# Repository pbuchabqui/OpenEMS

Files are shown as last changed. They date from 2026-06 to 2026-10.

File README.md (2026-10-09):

# OpenEMS

Fonte unica da verdade do projeto OpenEMS.

## Objetivo

OpenEMS e uma ECU para motores a combustao interna, atualmente focada no STM32H562RGT6. O codigo deve priorizar baixa latencia, baixo jitter e previsibilidade temporal para controle de injecao, ignicao, sensores e comunicacao de calibracao.

Este documento substitui os documentos historicos de plano, status e revisao. Qualquer decisao tecnica duravel deve ser atualizada aqui, nao em novos arquivos Markdown paralelos.

## Guia De Instalacao (10 passos)

Tudo pelo dashboard proprio (`tools/openems_dash`, aba **Install**: um guia
passo a passo com faixas validadas, lampada de ponto, teste de saidas, gravar,
exportar/importar tune e restaurar padroes de fabrica). O TunerStudio
(`tools/ts/openems.ini`, menu Install) continua funcionando como alternativa. Parametros
obrigatorios: **6** (cilindrada, vazao do injetor, AFR estequiometrico, curva
de dead time, offset do trigger, polaridade CKP/CMP). O resto ja vem com
valores de fabrica utilizaveis.

1. **Ligacao.** Roda 60-2 no CKP (PA0) e sensor de fase no CMP. Sensor Hall
   open-collector (repouso alto): polaridade "falling" (page0 byte 258).
2. **Motor** (Install → 1): cilindrada (cc), vazao do injetor
   (cc/min a 3 bar) e AFR estequiometrico (14.7 gasolina, 13.0 E30, 9.0 E100).
   Valor fora da faixa: so aquele campo e rejeitado, o resto e aplicado, e
   o canal `cfgReject` mostra qual campo (bit0 cilindrada, bit1 injetor,
   bit2 AFR, bit3 MAP ref, bit4 offset, bit5 EOI).
3. **Dead time do injetor** (Tuning → Injector Dead Time): copie a curva da
   folha de dados do injetor (ms vs tensao).
4. **Teste de saidas** (Install → 4, aba Outputs, motor parado): arme o teste;
   cada botao dispara um pulso no injetor ou bobina escolhidos. Confirme que
   injetor 1 e bobina 1 sao do cilindro 1, etc. "Exit" no fim (sai sozinho
   apos 5 s sem comando ou se o motor girar).
5. **Offset do trigger, grosso:** conte os dentes do primeiro dente apos a
   falha ate o PMS do cilindro 1 (compressao). Offset = (720 − dentes × 6) mod 720.
   Ex.: PMS 14 dentes depois → 720 − 84 = 636.
6. **Primeira partida:** sem pedal. O status `syncFull` deve acender e o RPM
   ficar estavel. Combustivel de partida = REQ_FUEL × multiplicador por CLT,
   igual com ou sem sensor de fase.
7. **Offset fino com lampada de ponto** (Install → 6): motor em marcha lenta,
   lampada no cabo da vela 1, ligue "Timing light mode" (centelha fixa em
   10.0°, sem correcoes nem knock). Ajuste "Trigger tooth0 offset" (1°) e
   "Fine offset" (0,1°) ate a lampada marcar 10°. Desligue o modo e grave
   (Burn). O modo nunca fica gravado: sempre desliga ao ligar a ECU.
8. **VE em marcha lenta:** com sonda wideband, ajuste a celula de VE da
   marcha lenta ate lambda ≈ alvo; depois ligue o closed loop e deixe o
   LTFT aprender o resto.
9. **Tabela de avanco:** comece conservador; o canal "Advance" mostra o
   avanco enviado as bobinas com 0,1° de resolucao (−20° a 60°). Knock
   atrasa so o cilindro que detonou.
10. **Gravar tudo** (Install → 7) antes de desligar. Exporte o tune para
    guardar uma copia; "Restaurar padroes de fabrica" volta aos valores do
    firmware (`tools/openems_dash/base_tune.json`, gerado do proprio firmware).

## Plataforma Alvo

- MCU: STM32H562RGT6, Cortex-M33.
- Revisao de silicio considerada: X.
- Linguagem: C++17 embarcado.
- Restricoes: sem STL em caminho critico, sem alocacao dinamica em runtime, sem excecoes.
- Build atual: `make firmware` gera `.elf`, `.hex` e `.bin` em `/tmp/openems-build`.

## Regras De Arquitetura

O fluxo de dependencias e descendente:

```text
APP     protocolos, calibracao, diagnostico
ENGINE  calculos de motor, agendamento angular, tabelas
DRV     decodificacao CKP/CMP, sensores, servicos independentes de MCU
HAL     registradores e perifericos STM32H562
HW      timers, ADC, GPIO, USB, CAN
```

Regras praticas:

- `APP` nao deve entrar no caminho critico de captura/agendamento.
- `ENGINE` decide tempo, angulo, pulso, dwell e estrategia.
- `DRV` transforma sinais fisicos em eventos de motor confiaveis.
- `HAL` contem apenas detalhe de periferico.
- O codigo ativo deve usar somente perifericos e nomes STM32H562 reais, sem aliases de compatibilidade.
- **`ENGINE` e `DRV` nao incluem headers `app/`.** Sinais de veiculo (marcha, velocidade, roda) entram via `engine/vehicle_inputs.h` (implementacao em `app/vehicle_inputs_bridge.cpp` → `can_rx_map`).
- **INJ/IGN GPIO:** mapas BSRR e write hot-path em `hal/out_pins.h` (`out_pin_write` inline). Init/safe em `out_pins_hw_init()`. `ecu_sched` nao reimplementa tabelas de pinos.
- Novos documentos Markdown paralelos nao devem ser criados; atualize este `README.md`.

## Escopo: so o firmware Hall

Este repo mantem um unico firmware: roda 60-2 + sensor de fase Hall, captura
em TIM5. A antiga regra "dual-firmware" (espelhar toda mudanca num tree de
encoder MT6835) foi abandonada na revisao de 2026-10; o tree encoder, se
retomado, porta as mudancas por conta propria.

## Pipeline De Controle Do Motor

### 1. Captura CKP/CMP

- Modulo principal: `src/drv/ckp.cpp`.
- Backend STM32: `src/hal/stm32h562/timer.cpp`.
- Timer usado: TIM5.
- Canais:
  - CKP: TIM5 CH1 em PA0.
  - CMP: TIM5 CH2 em PA1.

A captura mede bordas do virabrequim e comando, detecta dente faltante e alimenta a maquina de sincronismo. Classificacao por razao r = periodo / periodo de referencia:

- r < 0,5: ruido; descartado sem mover a referencia (o dente seguinte e medido certo).
- 0,5 ≤ r < 1,5: dente.
- r ≥ 1,5: candidato a gap; em FULL_SYNC so e aceito com exatamente 57 dentes desde o ultimo gap. Dente perdido ou a mais = perda de sync explicita, nunca ±6° silencioso.
- Pulso de ruido logo apos um dente curto e substituido quando o par fecha um periodo limpo.

Estados principais:

- `WAIT_GAP`: aguardando padrao confiavel de gap.
- `HALF_SYNC`: fase angular parcial suficiente para estrategias de partida rapida.
- `FULL_SYNC`: fase e ciclo conhecidos para injecao sequencial e ignicao correta.
- `LOSS_OF_SYNC`: falha de coerencia, ruido, timeout ou perda de padrao.

### 2. Quick Crank E Pre-Sync

- Modulos principais: `src/engine/quick_crank.cpp`, `src/engine/ecu_sched.cpp`.
- Objetivo: permitir primeira combustao antes do full sync quando tecnicamente seguro.

Estrategias permitidas antes de full sync:

- Injecao simultanea durante cranking.
- Injecao semi-sequencial quando a fase parcial permitir.
- Ignicao wasted spark antes da confirmacao completa de fase.
- Sem sensor de fase o motor roda em wasted spark por pares (0↔3, 1↔2), cada bobina no seu PMS.

A estrategia pre-sync deve degradar para modo conservador se houver duvida de fase. Partida rapida nao pode vencer seguranca de sincronismo.

### 3. Calculos De Combustivel E Ignicao

- Laco de 2 ms (sensores → PW/avanco/dwell → agendador): `src/engine/engine_calc.cpp` (`engine_calc_step`), testado de ponta a ponta em `test/test_engine_calc.cpp` e no motor virtual; `main_stm32.cpp` so le sensores, chama e publica telemetria.
- Combustivel: `src/engine/fuel_calc.cpp`.
- Ignicao: `src/engine/ign_calc.cpp`.
- Tabelas: `src/engine/table3d.cpp`.
- Sensores: `src/drv/sensors.cpp`.

Fluxo esperado:

```text
ADC/TIM6 -> sensors -> fuel_calc/ign_calc -> ecu_sched -> TIM5_CH3/BSRR -> atuadores
```

Os calculos usam RPM, MAP, TPS, CLT, IAT, lambda e calibracoes. Tabelas devem operar com interpolacao deterministica e sem custo imprevisivel no caminho critico.

Combustivel por speed density com oraculo fisico nos testes (`test/test_fuel_physics.cpp`): PW = REQ_FUEL × VE × MAP/101,325 kPa × T_ref/T, ΔP do injetor por √ΔP, filme de parede X-τ (Aquino), LTFT integrando o STFT. Interpolacao de tabelas e curvas arredonda ao mais proximo (sem vies). Partida: REQ_FUEL × multiplicador(CLT), igual em HALF e FULL sync.

Avanco em decimos de grau de ponta a ponta (tabela interpolada a 0,1°, correcoes em 0,1°, faixa unica −20° a 60°). Retardo de knock por cilindro (`ecu_sched_set_cyl_retard_x10`). O laco de 2 ms recalcula e faz commit a cada tick (`ecu_sched_commit_calibration_x10`).

### 4. Scheduling De Injecao E Ignicao

- Modulo principal: `src/engine/ecu_sched.cpp`.
- Injecao **e** ignicao: mesmo dispatcher **TIM5_CH3** (output compare) + fila
  ordenada de eventos absolutos; a saída física é feita por **GPIO BSRR**
  (`hal/out_pins.h`, `out_pin_write` inline). Sem TIM2/TIM8 OC no caminho INJ/IGN.
- Base temporal: TIM5 32-bit @ **62.5 MHz** (16 ns/tick), livre-corrente e
  partilhado com a captura CKP/CMP (CH1/CH2).

Premissa de projeto:

- O caminho critico é agendado por hardware output compare (TIM5_CH3): o OC arma
  o tick de despacho e a ISR escreve o BSRR do canal — não há bit-bang em espera.
- A ISR arma o proximo evento e actualiza estado; a escrita GPIO só é permitida
  header-inline (`out_pin_write`), nunca lógica de fila noutro `.cpp`.
- Janelas longas devem lidar com limite de contador por rearmamento/near-time, sem perder precisao perto do evento.
- Eventos vencidos devem ser tratados explicitamente, nunca silenciosamente aceitos.

Precisao (medida no motor virtual, `make precision-test`):

- SPARK e INJ_ON sao angulares: tabela por dente (dente de armamento + fracao
  1/256 de dente), ancorada na captura do dente, nao no instante da ISR.
  Eventos dentro do gap (348–360°) sao agendados corretamente.
- INJ_OFF = INJ_ON + PW em ticks; DWELL_START = centelha − dwell em ticks:
  largura de pulso e dwell exatos em tempo, independentes de aceleracao.
- Erro de centelha ≤ 0,01° em regime, ≤ 0,5° a ±2700 rpm/s, ≤ 0,2° com jitter de 1 µs.

Eventos de injecao e ignicao ficam codificados no scheduler do motor, nao num
driver legado. O scheduler recebe dentes/angulo do CKP, calcula quando cada canal
deve abrir/fechar (INJ) ou fazer dwell/centelha (IGN) e insere-os na mesma fila
despachada por TIM5_CH3. Ordem de canais BSRR em `docs/hw/pinout.md`.

### 4a. Detecção De Knock (Detonação)

- Sensor piezoelétrico knock conectado em PA5/ADC1_IN6.
- Hardware: filtro passa-banda externo → PA5 → ADC1.
- Detecção: software via threshold ADC (STM32H562 não possui periférico COMP).
- Amostragem: `knock_adc_update(raw)` chamado de `sample_fast_channels()` 12×/rev (acumulador `kFastSamplesPerRev`, não a cada dente CKP) durante janela ativa.
- Threshold ADC: padrão 2048 (12-bit), range [256, 4000].
  - Adaptativo: -64 por evento de knock; ciclos limpos devolvem +32, nunca acima do valor calibrado (sem deriva que desligue a deteccao).
- Janela de knock: `knock_window_cycle_end()`/`knock_window_open()` ligados a `arm_channel()` no evento `ECU_ACT_DWELL_START` (modo sequencial), atrás da flag `EMS_KNOCK_HW_PRESENT` (`hal/board_pinout.h`, default 0 — front-end analógico DNP na v1, `docs/hw/schematic/10_knock_dnp.md`). Com a flag em 0 a janela nunca abre de facto.
- Retardo: +2,0° por evento de knock, máximo 10,0°.
- Recuperação: -0,1° por ciclo limpo após 10 ciclos consecutivos limpos.
- Retardo por cilindro: so a bobina do cilindro que detonou atrasa.
- Persistência NVM: retardo em slot knock; o threshold nao e gravado (volta ao calibrado no boot).

### 5. Atuadores e pinout (firmware)

**Pinout completo: [`docs/hw/pinout.md`](docs/hw/pinout.md)** — mapa por pino dos
dois packages, conflitos WeAct e fiação. Código de referência: `ecu_sched.cpp`
(INJ/IGN BSRR), `hal/out_pins.h` (`static_assert` por board), `etb_driver.cpp`,
`timer.cpp`, `adc.cpp`. O firmware selecciona o package no **build**:

```bash
make firmware BOARD=rgt6   # default — WeAct LQFP64 (INJ/IGN em A/B/C)
make firmware BOARD=vgt6   # LQFP100 (INJ/IGN/ETB em PE*, BSRR único)
# bins: /tmp/openems-build/bin/openems-{rgt6,vgt6}.bin
```

Resumo das diferenças (o RGT6 **não tem port E** → INJ/IGN/ETB redistribuídos):

| Função | **RGT6** (default) | **VGT6** |
|---|---|---|
| CKP / CMP | PA0 / PA1 (TIM5) | igual |
| UART / USB / CAN / LED | PA9-10 / PA11-12 / PB8-9 / PB2 | igual |
| INJ1–4 | PA15 / PB3 / PC10 / PC11 | PE0 / PE2 / PE4 / PE6 |
| IGN1–4 | PC6 / PC7 / PC8 / PC9 | PE9 / PE11 / PE13 / PE15 |
| ETB PWM / DIR | PA6 (TIM3) / PA8 / PB4 | PE5 (TIM15) / PE7 / PE8 |
| INJ/IGN drive | GPIO BSRR (A/B/C) | GPIO BSRR (só GPIOE) |

ADC (comum aos dois): MAP PA3 · TPS PA4 · KNOCK PA5 · ETB_TPS1/2 PA2/PC5 · APP1/2
PC0/PC2 · CLT PB0 · IAT PB1 · FUEL_P PC4 · OIL_P PC1 · EWG_POS PC3. WBO2 λ só via
CAN (sem ADC O2). Tabela ADC completa (ADC1/2 + INP): `docs/hw/pinout.md`.

**Trocar de placa:** gravar o binário correcto (`BOARD=…`); flash cruzado = pinos
errados. Boot safe: `ecu_sched_outputs_safe_early()` → `out_pins_hw_init()`
(RGT6: PA15 JTDI pull-up; VGT6: PE\* LOW). Actuadores active-high.

## ADC E Sensores

- Modulos: `src/hal/adc.cpp`, `src/hal/stm32h562/adc.cpp`, `src/drv/sensors.cpp`.
- ADC primario/secundario representam ADC1/ADC2 no STM32.
- ADC 12-bit 0–3.3 V (raw 4095), tensão aceite pelo STM32H5. MAP 0–3.3 V → 0–3.00 bar (`raw × 3000 / 4095`). TPS/APP/ETB default 0–4095.
- TIM6 deve ser o gatilho periodico de amostragem.
- Validacao de sensores deve bloquear valores absurdos e preservar estado de falha para diagnostico.

## Comunicacao

- Protocolo em `src/app/ui_protocol.cpp`, dual-mode com auto-detect por frame:
  - **Legacy** (ASCII cru, sem envelope): comandos `Q/S/F/C/A/O/r/w/x/b/d/B/G/P/V/D`,
    usados por `tools/openems_dash/protocol.py`, `tools/lib/ecu_link.py`, HIL e diag.
  - **TunerStudio** (envelope `msEnvelope_1.0`): `[size u16 BE][cmd+dados][CRC32 BE]`;
    detectado quando o primeiro byte em IDLE e < 0x20 (byte alto do size). Respostas
    levam response code (0x00 OK, 0x82 CRC, 0x83 cmd, 0x84 range, 0x85 busy) + CRC32.
    Projeto TunerStudio: `tools/ts/openems.ini` (assinatura `OpenEMS_v1.2`).
    No envelope, `w` e chunk-write **RAM-only**; burn e explicito via `b`.
- Burn de Flash via protocolo (`w` legacy sem RAM-only, `b` em ambos os modos) e
  bloqueado quando `rpm_x10 > kFlashWriteSafeRpmX10` (errata ES0565: primeira
  escrita/erase pode congelar fetch ~120 us). Legacy devolve NACK; envelope 0x85.
- Pagina 11 (64 B): eixos das tabelas 16x16 (16xu16 RPM + 16xu16 load bar x100),
  editaveis com validacao de monotonicidade estrita; NVM setor 10 (slot 9).
- MVP de bancada: UART 115200 8N1 em `USART1` (`PA9=TX`, `PA10=RX`). O shuttle
  UART<->protocolo roda no slot de 2 ms (`comms_pump()`), nao-bloqueante, com
  TX FIFO (FIFOEN) — throughput efetivo ~4 kB/s, suficiente para realtime TS a
  10-20 Hz. USB CDC espelha o TX e mantem RX no slot de 20 ms.
- USB CDC: driver USB DRD FS completo (`hal/stm32h562/usb_cdc.cpp`), ainda nao validado em
  hardware; ate la a UART e o transporte de referencia.
- CAN/FDCAN: diagnostico e integracao com sensores externos.

Comunicacao nao deve bloquear decode, sync, scheduling ou atuadores.

## Errata STM32H562 ES0565

Referencia local revisada: `es0565-stm32h562xx563xx573xx-device-errata-stmicroelectronics.pdf`, Rev 8, January 2026.

Impactos diretos no projeto:

- Revisao operacional considerada: X. Antes de teste real, confirmar a revisao fisica por marcacao do chip e `REV_ID` em `DBGMCU_IDCODE`, e registrar essa evidencia antes de liberar ensaio com atuadores.
- PA1 tem errata de histerese na revisao A: a histerese de entrada de PA1 so e habilitada quando PA0 esta configurado como entrada. Como CMP usa `PA1/TIM5_CH2`, revisao A exige condicionamento externo robusto ou troca de pino/placa. Em revisoes Z/X/W a limitacao consta como ausente.
- Flash tem limitacao de endurance de 1 kcycle nas revisoes A/Z. NVM/calibracao/seed de sincronismo nao podem gravar com alta frequencia. Para teste real, tratar Flash como recurso de baixa taxa e preferir commit explicito/event-driven.
- A primeira operacao de erase/program apos power-on ou Standby pode congelar fetch/read de Flash por cerca de 120 us. O caminho critico de CKP/scheduler nao deve depender de escrita Flash durante motor girando. Workaround completo exige vetor/handlers criticos e rotina da primeira escrita em SRAM.
- Read-while-write em Flash aumenta latencia em revisoes A/Z. Nao executar erase/program em Bank2 durante janela critica de injecao/ignicao/CKP.
- ADC: manter amostragem regular disparada por TIM6. Nao usar fila de conversoes injetadas, modo dual interleaved, watchdog analogico misturado com canais nao guardados ou stop de conversao injetada sem aplicar os workarounds da errata.
- FDCAN: nao habilitar edge filtering (`EFBI`) e evitar mistura de dedicated Tx buffer com Tx FIFO em prioridades diferentes. Se FDCAN1/FDCAN2 forem usados juntos, manter o mesmo nivel TrustZone/privilegio nos dois. O backend atual deve permanecer simples: sem edge filtering e com disciplina de fila unica/buffer unico.
- USB: em transferencias OUT, a SRAM USB pode ainda estar sendo atualizada quando o CTR dispara. Driver USB real deve inserir atraso minimo antes de ler buffer OUT: 800 ns em Full Speed.
- TIM: conexao de USB SOF para TIM2/TIM5 ITR12 pode falhar; o projeto nao deve usar USB SOF como referencia temporal de motor. Toda a base temporal do motor (captura CKP/CMP e dispatcher de INJ/IGN) vive em TIM5 e nao depende de USB SOF.
- IWDG nao acorda o sistema de Stop mode. O projeto de ECU nao deve depender de Stop mode para recuperacao por watchdog.

Conclusao operacional: considerando silicio Rev X, a limitacao de histerese em PA1/CMP e as limitacoes de endurance/read-while-write de Flash das revisoes A/Z nao sao bloqueios esperados. Continuam relevantes em Rev X: congelamento da CPU na primeira escrita/erase de Flash, cautelas de ADC, FDCAN, USB, TIM USB SOF e IWDG em Stop mode. Placa WeAct e firmware atual seguem adequados para bancada sem atuadores energizados. Teste real de motor ainda exige confirmar fisicamente a Rev X, limitar escrita Flash durante motor girando e validar USB/FDCAN/ADC com os workarounds acima.

## Build

Compilar objetos do firmware:

```bash
make firmware
```

Executar regressao host minima do MVP de bancada:

```bash
make host-test
```

Limpar artefatos:

```bash
make clean
```

## Higiene De Codigo

Programa de qualidade do monorepo (concluido 2026-07; HEAD tipico inclui
`fa36aab` e anteriores `713d4a8`…`bce2f4a`). Objectivo: reviews limpos, zero
warnings com `WERROR`, camadas enforcadas e caminho critico de actuadores
isolado sem big-bang rewrite.

### Gates locais (obrigatorios antes de merge)

```bash
make ci-local                   # todos os gates abaixo
# equivalentes manuais:
make secrets-check
make host-test WERROR=1         # referencia: 1341 PASS / 0 FAIL
make precision-test             # motor virtual: 120 PASS / 0 FAIL (centelha, dwell, PW, EOI)
make ini-check                  # TunerStudio ini: referencias, sobreposicao, faixas = firmware
make dash-check DASH_PY=<venv>/bin/python  # dashboard: helpers JS + protocolo vs ECU simulada
make sim-ecu NVM=/tmp/nvm.bin   # ECU simulada num pty para o dashboard (sem placa)
make firmware-rgt6 WERROR=1
make firmware-vgt6 WERROR=1
make lint-includes LINT_PHASE=A LINT_ERROR=1   # ban ENGINE/DRV → app/
make lint-includes LINT_PHASE=B LINT_ERROR=1   # ban ENGINE → hal/regs.h (allowlist)
make format                     # clang-format so em ficheiros dirty (on-touch)
```

| Gate | Target | Notas |
|---|---|---|
| Warnings | 0 com `-Wall -Wextra` | Host **e** firmware dual board |
| Secrets tracked | 0 | `**/wifi_credentials.h` gitignored |
| Layering A | 0 includes `app/` em `src/engine`, `src/drv` | `tools/lint_includes.py` |
| Layering B | `hal/regs.h` so em engine com allowlist | `tools/include_allowlist.txt`: `ecu_sched` (TIM5), `auxiliaries` (fan/pump ate Phase C) |
| Host tests | PASS exacto estavel | Suites em `test/test_*.cpp` + `run_all.cpp` |
| Dual board | bins rgt6 + vgt6 | Qualquer mudanca de pin/HAL |

### Layout de testes host

| Ficheiro | Papel |
|---|---|
| `test/harness.{h,cpp}` | `CHECK_*`, contadores PASS/FAIL |
| `test/fixtures.{h,cpp}` | setup ADC/ETB, `ckp_fire` / `cam_fire` |
| `test/ui_helpers.{h,cpp}` | envelope TunerStudio para testes de protocolo |
| `test/run_all.cpp` | `main()` — **ordem fixa** das suites |
| `test/suite_registry.h` | declaracoes das funcoes `test_*` |
| `test/test_*.cpp` | suites (etb, torque, ckp, fuel, sched, protocol, …) |
| `test/sim/engine_sim.{h,cpp}` | motor virtual: cinematica θ(t), roda 60-2 real + came, jitter/ruido, modelo de latencia da ISR, log de pinos com timestamp |
| `test/sim/precision_main.cpp` | `make precision-test`: compara o que o motor recebe (angulo de centelha, dwell, combustivel, EOI) com o oraculo cinematico; defeitos conhecidos = XFAIL com a etapa que os corrige |

Host: um unico TIM5 simulado (`hal/tim5_host.h`) e partilhado por captura
CKP/CMP, comparador do scheduler e `tim5_count()`; `out_pin_write` expoe um
hook (`out_pins_host::write_hook`) para o simulador registar cada transicao.

Nao reintroduzir monolitio `mvp_bench_tests.cpp`. Novos testes: ficheiro de suite
existente ou novo `test_*.cpp` + registo em `run_all.cpp` e `suite_registry.h`.

### Camadas — contratos pos-higiene

**Vehicle inputs (ENGINE ← APP):**

```text
can_stack → can_rx_map_process (APP)
torque_manager / auxiliaries → vehicle_gear|speed|wheel (engine/vehicle_inputs.h)
                            → vehicle_inputs_bridge.cpp (APP) → can_rx_*
```

Page0 serialize/apply do mapa CAN permanece em APP (`can_rx_map_*_page0`).

**INJ/IGN outputs (HAL):**

```text
ecu_sched gpio_set_pin → ems::hal::out_pin_write  (inline em out_pins.h)
ecu_sched_outputs_safe_early → out_pins_hw_init()  (clocks + MODER + BSRR LOW)
```

Ordem de canais BSRR = `ECU_CH_*`:
`[INJ3, INJ4, INJ1, INJ2, IGN4, IGN3, IGN2, IGN1]`. Actuadores active-high;
safe = LOW. Testes de polaridade RGT6: `test_out_pins_bsrr_rgt6`.

Hot-path rule (`ecu_sched_internal.h`): nao mover `evt_insert` / arm / dispatch
para outro `.cpp`; write GPIO so e permitido se **header-inline** (como
`out_pin_write`).

**NVM boot:** loaders de tabelas/correccoes em `app/nvm_boot.cpp`
(`nvm_boot_load_tables(cal_layout_ok)`), chamados de `main_stm32` — mesma
ordem e gate de layout de antes.

**UI protocol:** `ui_protocol.cpp` (parse + API) + `ui_protocol_state.cpp` +
`ui_protocol_pages.cpp` + `ui_protocol_envelope.cpp` + `ui_protocol_internal.h`.

**ETB PWM:** API preferida `etb_pwm_init` / `etb_pwm_set_duty_x10`. Aliases
`tim15_etb_*` deprecated em `hal/timer.h`.

### Secrets e vendor

- WiFi tools ESP32: copiar `wifi_credentials.example.h` → `wifi_credentials.h`
  (nunca commitado). Se password ja esteve no historico git, **rodar no AP**.
- `graphify-out/` e bins/fonts pesados do `ardustim_gui` nao sao versionados
  (regenerar graphify / `npm install` localmente). GUI Electron continua
  documentada em `tools/esp32_combined/README.md`.

### Docs

| Documento | Papel |
|---|---|
| **README.md** (este) | Fonte unica de decisoes duraveis |
| `docs/bench_test_manual.md` | Teste de bancada na WeAct VGT6 (sem atuadores) |
| `docs/hw/pinout.md` | **Pinout completo** RGT6/VGT6 (detalhe movido do §5) |
| `docs/wiring_diagram.md` | Esquemáticos eléctricos (mapa de pinos ASCII **legado**) |
| `docs/ROADMAP.md` | Backlog de produto (ADC residual, SD, …) |
| `docs/*.md` | Subsistemas (fuel, idle, …) |

### Fora de escopo do programa de higiene (opcional)

- `hal/aux_gpio` para fan/pump (hoje `auxiliaries.cpp` ainda usa `regs.h` /
  BSRR — allowlist Phase C).
- Split adicional de monolitios grandes (`ckp.cpp`, `fuel_trim`, etc.).

## MVP Bancada Segura

Definicao de pronto para o MVP de bancada:

- `make firmware` gera `.elf`, `.hex` e `.bin`.
- `make host-test` cobre regressao minima (suites em `test/test_*.cpp` + `run_all.cpp`): CKP 60-2, quick crank, scheduler, tabelas, protocolo UI, ETB, torque, fuel/ign, X-τ, etc.
- Firmware sobe na STM32H562 com ST-Link, sem bobinas/injetores energizados, sem reset loop ou hard fault.
- TIM5 recebe CKP/CMP sintetico de 200 a 8500 rpm e telemetria mostra transicoes `WAIT_GAP`, `HALF_SYNC`, `FULL_SYNC`, perda e retomada de sync.
- As saídas INJ/IGN (GPIO BSRR, despachadas por TIM5_CH3) geram sinais verificaveis em osciloscopio para cranking, half-sync, full-sync, loss-of-sync e zero RPM.
- ETB (PWM PA6/TIM3 no rgt6, PE5/TIM15 no vgt6) permanece desligado até `etb_cal_valid==1 && !throttle_fault_bits`.
- UI bridge usa UART `PA9/PA10` a 115200 8N1 para assinatura, realtime data e escrita pequena de calibracao.
- Durante ensaio, registrar `loop2_last`, `loop2_max`, `late_event_count`, `cycle_schedule_drop_count` e `calibration_clamp_count`.

### CAN TX Frames

| ID | Cadência | Layout |
|---|---|---|
| 0x400 | 10 ms | RPM(2LE) · MAP_kpa(1) · TPS_pct(1) · CLT+40(1) · advance+40(1) · PW_x10(1) · StatusBits[7:0](1) |
| 0x401 | 100 ms | FuelP_kpa(2LE) · OilP_kpa(2LE) · IAT+40(1) · STFT+100(1) · StatusBits[15:8](1) · VVT_ex_pct(1) |
| 0x402 | 500 ms | FuelAccum_ul(4LE) · FuelDelta_ul(2LE) · reservado(2) |

### Status Bits (16-bit, split entre 0x400 e 0x401)

- Bits 0-7 transmitidos em `0x400 data[7]`; bits 8-15 em `0x401 data[6]`.
- Bits definidos em `src/app/status_bits.h`:
  - `STATUS_SYNC_FULL` (bit 0): sincronismo CKP/CMP completo.
  - `STATUS_PHASE_A` (bit 1): fase parcial disponível.
  - `STATUS_SENSOR_FAULT` (bit 2): falha em sensores analógicos.
  - `STATUS_LIMP_MODE` (bit 3): modo de emergência ativo.
  - `STATUS_ETB_LIMP` (bit 4): ETB em modo limp (limite reduzido).
  - `STATUS_XTAU_LEARN` (bit 5): autocalibracao X-τ em progresso.
  - `STATUS_SCHED_LATE` (bit 6): evento de scheduler atrasado.
  - `STATUS_SCHED_DROP` (bit 7): evento descartado no scheduler.
  - `STATUS_SCHED_CLAMP` (bit 8): ajuste limitado na calibracao — em `0x401 data[6]` bit 0.
  - `STATUS_WBO2_FAULT` (bit 9): sensor WBO2 offline — em `0x401 data[6]` bit 1.
  - bit 10 reservado (era TLE8888_FAULT; sempre 0), `STATUS_IGN_SEQUENTIAL` (bit 11), `STATUS_REV_LIMIT` (bit 12).
  - `STATUS_LAUNCH_ACTIVE` (bit 13): launch control holding ETB/RPM.
  - `STATUS_TC_ACTIVE` (bit 14): traction control reducing torque.
  - OCH also exposes `tcReduction` (%×10 @ off 45) and `torqueSparkRetard` (deg @ off 47).

### ETB (Electronic Throttle Body)

- PWM: **PA6 TIM3_CH1** (rgt6) ou **PE5 TIM15_CH1** (vgt6), 20 kHz (`etb_pwm_init`).
- H-bridge dual-DIR (BTS7960/VNH5019-style): IN1 open / IN2 close — rgt6 **PA8/PB4**,
  vgt6 **PE7/PE8** (ver `docs/hw/pinout.md`).
- Boot policy: ETB desativado (`EN=0`, PWM=0) até calibracao valida e sensores OK.
- **Auto-cal de power-on** (`src/engine/etb_autocal.{h,cpp}`): a cada boot varre a
  borboleta aos batentes (fechado→aberto) no tick de 2 ms, ANTES do torque manager
  assumir, e aplica os limites TPS1/TPS2 em RAM. Aborta mantendo a cal de flash se o
  motor girar, o driver faltar ou o curso for implausível (span/invertido). O
  `EtbCalRecord` (16 B, magic `EC` + CRC-32, setor adaptativo) persiste a última cal
  boa como **fallback** quando uma partida interrompe a varredura do power-on
  seguinte (`nvm_save_etb_cal` / `nvm_load_etb_cal`). O pedal (APP) continua manual.
- Plausibilidade dual-sensor (pinos = `src/hal/adc.cpp` / `docs/hw/pinout.md`):
  - APP plausibilidade: compara APP1 vs APP2 (**PC0 / PC2**), gera `THROTTLE_FAULT_APP_PLAUS` se delta exceder limite.
  - ETB_TPS plausibilidade: compara ETB_TPS1 vs ETB_TPS2 (**PA2 / PC5**), gera `THROTTLE_FAULT_ETB_PLAUS` se delta exceder limite.
  - Delta máximo default: 12% entre sensores redundantes.
- Falhas: `THROTTLE_FAULT_APP1/APP2/APP_PLAUS` bloqueiam demanda; `THROTTLE_FAULT_ETB_*` entram em limp mode com `etb_max_open_pct_x10_limp` (default 25%).
- RATE limits: `etb_max_rate_pct_per_s` (default 500 %/s).
- Gating do torque manager:
  - Falhas APP (`THROTTLE_FAULT_APP1/APP2/APP_PLAUS`): limitam abertura do ETB (limp home) mas nao desativam o enable request.
  - Falhas ETB (`THROTTLE_FAULT_ETB_TPS1/ETB_TPS2/ETB_PLAUS`): desativam o enable request do ETB via `etb_enable_request = false`.

### X-τ Autocalibracao

- Executa no slot 100ms, gated por: RPM > 2000, STFT ±500 limites, lambda valido, AE inativo.
- Bloqueio de intervalo: `kLearnIntervalMs = 60000u` (mínimo 60s entre aprendizados consecutivos).
- Deadband STFT: não aprende quando `|STFT| <= 20` (±20% deadband).
- Ajuste lento: 1 LSB por minuto max, clamp aos limites de tabela (1..255 ciclos).
- Persistencia: RAM only, salva em NVM page 6 via burn explícito (nunca durante motor girando).
- Safety: nunca executa erase/program durante janela critica de CKP/scheduler.

Fora do MVP de bancada:

- Primeira partida de motor real.
- USB CDC real.
- Operacao com atuadores reais energizados sem validacao previa de pinout, polaridade, cargas dummy e limites de Flash.

## Estado Atual

- Codigo ativo direcionado ao STM32H562.
- Backend de timers STM32: TIM5 (CKP/CMP + dispatcher INJ/IGN CH3), TIM6 (trigger ADC), TIM2 (EWG PWM), TIM3 (ETB PWM rgt6), TIM15 (ETB PWM vgt6), TIM4 (VVT).
- Scheduler principal consolidado em `src/engine/ecu_sched.cpp`.
- Fonte ativa nao deve conter aliases de compatibilidade herdados de outras plataformas.
- `make firmware` e `make host-test` devem continuar passando antes de qualquer entrega de MVP de bancada.
- Esta pagina e a unica fonte de verdade documental do projeto.

## Proximos Passos De Hardening

### Feito no firmware (defensivo — 2026-07-16)

- Cranking/idle harden: `quick_crank_update` 1×/tick (HALF+FULL); `is_cranking`/`is_afterstart`
  gates AE/STFT/X-τ (não só RPM&lt;exit); flood-clear APP≥70% corta fuel+prime; ETB open-loop
  em crank (`etb_idle_max`) + taper 1 s + histerese RPM de idle phase.
- Fuel angular: FULL = VE/running; **HALF+cranking** = batch SIMULTANEOUS (REQ×mult+min_pw,
  sem VE/STFT/AE); corte imediato em exit-crank / flood / protect / !sync.
- Prime + protect: prime bloqueado se flood/protect/half-lockout/rev-limit; `force_output`
  honra inj/ign inhibit (prime não bypassa mask); boot com mask=0x0F e `inj_pw=0` até 1.º tick.
- CKP: sem `schedule_on_tooth` em SPIKE; hist contaminado → LOSS; sem wrap 57→0 sem gap.
- Scheduler: dwell WD arma no pin HIGH + purge no trip; inj inhibit = force OFF + purge fila; lead assinado wrap-safe.
- Scheduler: injector open WD (1.2× PW / hard 36 ms) + overflow da fila prefere dropar ON/DWELL (nunca OFF/SPARK se houver assert).
- Sensores: commit MAP/TPS/faults a cada amostra rapida (nao so no tick 100 ms).
- Limp: falha MAP corta combustivel a qualquer RPM; telemetria PW alinhada ao mask.
- Fuel: `calc_final_pw_us` clampa corr Q8 0.25–2.0× e satura a 100 ms; AE interp signed.
- Page0 apply: rev limit, STFT, decel hysteresis, CMP window, trim por cilindro clampados.
- EOI 2D RPM×CLT (page6 79-114): `eoi_rpm_axis_x10` / `eoi_clt_axis_x10` /
  `eoi_table_deg` (bilinear 3×3). Sem bump de magic v6; page0 164-168 deixa de
  guardar o blend 1D.
- Flash: layout **LTF3** = magic + CRC-32 dos mapas adaptativos; seed no mesmo
  SM de flush (sem erase independente do setor 0); seed finaliza magic/CRC.
- ETB: PID `etb_control_update` → `etb_driver_set_motor_pwm`; disable → shutdown.
- CKP: `ticks_to_ns`/gap/normal em math overflow-safe; CMP expected em u64; 1ª borda
  CMP só arma timestamp; LOSS zera `cmp_confirms` (exige 2 bordas p/ sequencial).
- Sched: flush fila + safe pins em transição presync↔sequencial.
- Protect: oil fault @ RPM>1500 corta fuel+ign; fuel-rail fault @ RPM>500 corta fuel.
- TS `openems.ini`: page0 80–85 closed-loop/LTFT; 175 layout ver; 176–190 LTFT authority/LEARN;
  191–215 Launch/TC; 216–251 CAN RX map (gear/vehicle/driven wheel); `ochBlockSize` = 86.
- TC slip: CAN wheel vs vehicle via `vehicle_inputs` (bridge → can_rx_map) →
  torque cut; else RPM-dot proxy.

### Pinout — estado

- **Dual board:** `make firmware BOARD=rgt6|vgt6` → `openems-rgt6.bin` / `openems-vgt6.bin` (`docs/hw/pinout.md`).
- **RGT6:** INJ PA15/PB3/PC10/PC11 · IGN PC6–9 · ETB PA6/PA8/PB4 · OIL PC1.
- **VGT6:** INJ PE0/2/4/6 · IGN PE9/11/13/15 · ETB PE5/7/8.
- **Mapas INJ/IGN:** `hal/out_pins.h` (fonte unica; `static_assert` por board).
- **Boot safe:** `ecu_sched_outputs_safe_early()` → `out_pins_hw_init()` logo apos
  clock (RGT6: PA15 JTDI; VGT6: PE* LOW). Actuadores active-high.
- **DFU:** `dfu-util -a 0 -s 0x08000000 -D openems-<board>.bin` + power-cycle BOOT0=0.
- **docs/wiring_diagram.md** stale (mapa de pinos ASCII legado) — pinout válido em `docs/hw/pinout.md`.

### P1 — restante (decode / cam / proteccao)

- ~~Math overflow-safe `ticks_to_ns` / CMP u64; 1ª borda CMP; LOSS zera `cmp_confirms`~~ → feito.
- ~~Flush fila + safe pins presync↔sequencial; oil/fuel-rail cut~~ → feito.
- ~~Pinout dual RGT6/VGT6 (`BOARD=`, board_pinout.h)~~ → no código.
- ~~Fuel HALF+crank batch + prime/protect + boot INJ LOW~~ → no código.
- ~~Fuel só em FULL_SYNC (HALF: spark wasted, inj inhibit); `close_cmp_seq_gate` em todos os drops de sync (incl. anomaly→WAIT_GAP, stall)~~ → feito.
- ~~Overtemp CLT 105/115 °C (WARN/CRIT) + DiagnosticManager CRITICAL → inj/ign inhibit~~ → feito.
- ~~Multi-spark: gate ≤1500 RPM; angle table 48 + event queue 48 (3 extras × 4 cyl); host margin test~~ → feito.
- DiagnosticManager: debounce/tick/persistência NVM ainda aspiracional (`protection_system.md`).

### P2 — bancada / HIL / docs

- Validar imagem `.bin` com ST-Link, sem bobinas/injetores no primeiro boot.
- Scope das saídas INJ/IGN (BSRR/TIM5_CH3, latência/jitter) e TIM5 CKP/CMP 200–8500 rpm.
- USB CDC real: IRQ/endpoints, sem bloqueio do caminho crítico; RX ≥ envelope.
- Host/HIL expandido: decode, sync, quick crank, scheduler, fuel/ign, sensores (já há host-test 1000+; HIL físico pendente).
- Actualizar `docs/wiring_diagram.md` (esquemáticos eléctricos) ao pinout de `docs/hw/pinout.md` (ainda tem mapa TIM2/PC legado no ASCII).

## Politica Documental

Este `README.md` e a fonte unica da verdade. Nao criar `STATUS.md`, `ROADMAP.md`, `PLAN.md`, `CLAUDE.md`, `spec.md` ou documentos similares paralelos. Se uma informacao precisa persistir, ela entra aqui ou vira comentario tecnico proximo ao codigo que a executa.

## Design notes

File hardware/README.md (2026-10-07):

# OpenEMS — hardware

Caminho de fabrico da ECU OpenEMS: projecto KiCad **próprio, desenhado de raiz**.
O microRusEFI é **referência**, não cobre (mudou em 2026-08-07 —
ver [`docs/hw/microruseefi_as_base.md`](../docs/hw/microruseefi_as_base.md)).

## Estrutura

```
hardware/
├── README.md                 ← este ficheiro
├── openems_v1/               ← ✅ projecto KiCad de produção (editar AQUI)
├── openems_ecu/              ← ⛔ fork mRE, CONGELADO (recuo + libs verificadas)
│   ├── rusefi_lib/           ← símbolos reutilizados pela board nova
│   ├── rusefi_lib_external/  ← footprints/libs mRE
│   └── hellen-one → vendor   ← só USB footprint (symlink)
└── vendor/
    └── hw_microRusEfi/       ← submodule git (referência imutável)
```

## Abrir no KiCad 7+

```bash
kicad hardware/openems_v1/openems_v1.kicad_pro     # produção
kicad hardware/openems_ecu/openems_ecu.kicad_pro   # congelado, só consulta
```

## Vendor (submodule)

```bash
git submodule update --init hardware/vendor/hw_microRusEfi
cd hardware/vendor/hw_microRusEfi && git submodule update --init --recursive
```

Só consultar / copiar libs. **Não** editar o vendor como board de produção.

## Documentação

| Doc | Papel |
|-----|---|
| [`docs/hw/microruseefi_as_base.md`](../docs/hw/microruseefi_as_base.md) | Decisão mRE + plano |
| [`docs/hw/netlist_v1.md`](../docs/hw/netlist_v1.md) | O que ligar a quê |
| [`docs/hw/pinout.md`](../docs/hw/pinout.md) | Pinos firmware H562 |
| [`docs/hw/mcu_f407_to_h562_pin_map.md`](../docs/hw/mcu_f407_to_h562_pin_map.md) | 6 pads F407→H562 |
| [`docs/hw/pinmap_logical.md`](../docs/hw/pinmap_logical.md) | Mapa lógico nets |

## O que **não** está aqui (de propósito)

- Scaffold `openems_interface_v1` (removido — não era fabricável)
- Clones avulsos de libs rusEFI/Speeduino sob `hardware/kicad/vendor`
- Hellen-One como base de ECU (só footprint USB via symlink)

## KiCAD MCP (AI assist)

Repo: [mixelpixx/KiCAD-MCP-Server](https://github.com/mixelpixx/KiCAD-MCP-Server.git)  
Install local: `/home/pedro/kicad-mcp-server` (git clone + `npm run build` + venv).

### Config Grok (`~/.grok/config.toml`)

O backend Python **tem** de ser o venv (tem `sexpdata`/`kicad-skip` **e** `pcbnew` via `--system-site-packages`).  
Se usar o `python3` do sistema, o processo Python morre ao arrancar →  
`Python process for KiCAD scripting is not running`.

```toml
[mcp_servers.kicad]
command = "node"
args = ["/home/pedro/kicad-mcp-server/dist/index.js"]
enabled = true
startup_timeout_sec = 60

[mcp_servers.kicad.env]
NODE_ENV = "production"
KICAD_PYTHON = "/home/pedro/kicad-mcp-server/.venv/bin/python"
PYTHONPATH = "/usr/share/kicad/scripting/plugins:/usr/lib/kicad/lib/python3/dist-packages"
LOG_LEVEL = "info"
KICAD_AUTO_LAUNCH = "false"
KICAD_BACKEND = "auto"
```

Reiniciar a sessão Grok após alterar o config. Verificar: `grok mcp list`.

### Actualizar o servidor

```bash
cd /home/pedro/kicad-mcp-server
git pull --ff-only
npm install && npm run build
.venv/bin/pip install -r requirements.txt
```

### Uso com OpenEMS

```bash
# 1) Abrir o projecto no KiCad GUI (opcional para IPC; útil para ver o resultado)
kicad hardware/openems_ecu/openems_ecu.kicad_pro

# 2) No Grok: tools do servidor "kicad"
#    - Esquemático: list_schematic_components, get_schematic_pin_locations, …
#    - PCB: open_board, get_component_pads, route_pad_to_pad, …
```

| Área | Estado neste monorepo |
|---|---|
| Esquemático `mcu_h562.kicad_sch` | OK via MCP (ex.: `list_schematic_components`) |
| PCB `openems_ecu.kicad_pcb` (~4 MB mRE) | `open_board` / `kicad-cli` plot podem **segfault** (SWIG + board grande) |
| Workaround plot | Vistas geradas a partir do `.kicad_pcb` (ex. PIL) se o plot falhar |

Diagnóstico rápido do backend:

```bash
# Tem de imprimir {"type":"ready"} e NÃO ModuleNotFoundError: sexpdata
echo '{}' | /home/pedro/kicad-mcp-server/.venv/bin/python \
  /home/pedro/kicad-mcp-server/python/kicad_interface.py
```

Sucessor do projecto (opcional): [Konnect](https://github.com/mixelpixx/Konnect) — plugin Rust nativo KiCad 10 / IPC.

## Créditos

Hardware base © rusEFI / microRusEFI. OpenEMS adapta com atribuição.

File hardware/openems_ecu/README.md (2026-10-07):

# OpenEMS ECU — KiCad (fork mRE) — ⛔ CONGELADO

> **Não editar. Não é a board de produção.** Desde **2026-08-07** o desenho de produção
> é [`hardware/openems_v1/`](../openems_v1/), um projecto KiCad em branco.
> Porquê da mudança: [`docs/hw/microruseefi_as_base.md`](../../docs/hw/microruseefi_as_base.md).
>
> Isto fica por dois motivos: é o **recuo** se o desenho novo encalhar, e guarda as libs
> verificadas em `rusefi_lib/` (`tle8888qk.lib`, Net-Tie, AMPSEAL) que a board nova reutiliza.
>
> Estado em que ficou: DRC **nunca passou**, 2 camadas de sinal (a v1 pede 4), e restam
> nets fantasma do mRE (ex. `/PE1`, que no H562 LQFP100 é VCAP).

Cópia de trabalho a partir de [rusefi/hw_microRusEfi](https://github.com/rusefi/hw_microRusEfi),
adaptada ao firmware OpenEMS (**STM32H562VGT6** + **TLE8888-2QK**).

## Abrir

```bash
kicad hardware/openems_ecu/openems_ecu.kicad_pro
```

## Sheets

| Ficheiro | Função |
|---|---|
| `openems_ecu.kicad_sch` | Raiz hierárquica |
| `openems_ecu.kicad_pcb` | Layout (base mRE + rework H562) |
| `mcu_h562.kicad_sch` | MCU **STM32H562VGTx** LQFP100 (activo) |
| `stm32.kicad_sch` | Arquivo F407 — **não** está na hierarquia |
| `TLE8888-1QK.kicad_sch` | Hub TLE8888 |
| `TLE9201SG.kicad_sch` | ETB H-bridge mRE |
| `adc.kicad_sch` | Entradas analógicas |
| `hi-lo.kicad_sch` | USB / níveis |
| `pair.kicad_sch` | Low-sides (×2) |
| `FlashMemory.kicad_sch` | Flash opcional |

## Libs

| Caminho | Uso |
|---|-----|
| `rusefi_lib/` | Símbolos legacy mRE (TLE, molex, …) |
| `rusefi_lib_external/` | Footprints / libs estendidas |
| `hellen-one` → `../vendor/hw_microRusEfi/hellen-one` | Footprint USB mini-B |

```bash
# Se libs faltarem após clone limpo:
git submodule update --init --recursive hardware/vendor/hw_microRusEfi
# rsync opcional a partir do vendor se rusefi_lib_external estiver incompleto
```

## Estado OpenEMS

1. ~~MCU H562 sheet~~ ✅ `mcu_h562.kicad_sch`, INJEN=`PE14`
2. ~~Rework 6 pads no PCB~~ ✅ VCAP×2, VDDUSB, VSSA/VSS; enables TLE→PE14/PE3
3. Auditoria TLE vs `docs/hw/tle8888_pinout.md`
4. Conector AMPSEAL 35+23 vs 48-pin mRE (aberto)
5. ETB TLE9201 vs BTS7960 (aberto)
6. DRC / refill zones / Gerber

Arquitectura: [`docs/hw/microruseefi_as_base.md`](../../docs/hw/microruseefi_as_base.md).

## Créditos

Hardware base © rusEFI / microRusEFI contributors.

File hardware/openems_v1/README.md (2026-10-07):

# OpenEMS ECU v1 — KiCad (produção)

Projecto KiCad **desenhado de raiz**. Nenhum cobre herdado.
Substitui o fork do microRusEFI em `../openems_ecu/` (congelado desde 2026-08-07 —
porquê em [`docs/hw/microruseefi_as_base.md`](../../docs/hw/microruseefi_as_base.md)).

Arquitectura activa: **v2** — TLE8888 saiu; entraram TPS65381A-Q1 / MC33810 / L9960T /
CJ125. Autoridade de pinos: [`docs/hw/pinout_v2.md`](../../docs/hw/pinout_v2.md).
Arquitectura: [`docs/hw/architecture_v2.md`](../../docs/hw/architecture_v2.md).

```bash
kicad hardware/openems_v1/openems_v1.kicad_pro
```

## Fase actual — só esquemático profissional

**Âmbito agora:** sheets KiCad correctas, legíveis, ERC limpo, docs de bloco alinhadas
a `pinout_v2.md`. Definition of done por sheet em
[`docs/hw/schematic/README.md`](../../docs/hw/schematic/README.md).

**Fora de âmbito até o esquemático fechar:**

- Placement, copper, pours, DRC de PCB, gerbers, PnP
- Footprint AMPSEAL 23 (bloqueia **layout** da sheet 09, não o desenho eléctrico do mapa
  de pinos no esquemático)
- Drivers de firmware dos CIs novos

O `.kicad_pcb` existe só como moldura (contorno + stackup de partida). **Não se trabalha
nele nesta fase.**

## Estado (2026-08-08)

| Item | Estado |
|---|---|
| Hierarquia root | ✅ renomeada p/ v2 2026-08-08 — `04_tle8888_hub`/`06_etb` substituídos por 04a–d; root agora A3 (13 sheets) |
| Stackup 4 camadas + contorno provisório | ✅ moldura only |
| Netclasses de partida | ✅ (valores a rever na fase PCB) |
| Sheet `01_power` | ✅ desenhada 2026-08-08, ERC 0 erros (13 avisos esperados) |
| Sheet `11_mcu_h562` | 🔄 desenhada, **limpeza ERC / title block** pendente |
| Sheets `03_cmp`, `07_flex` | ⚠️ rascunho — rever pinos e qualidade |
| Sheet `05_analog` | ⛔ rascunho no **mapa pré-v2** — **refazer**, não remendar |
| Restantes sheets | ❌ vazias |
| Símbolos TPS65381A / MC33810 / L9960T / CJ125 | ❌ em falta (bloqueiam sheets 04*) |
| PCB / copper | ⏸️ diferido |

## Hierarquia (v2)

Renomeada no root 2026-08-08 — `04_tle8888_hub` e `06_etb` (ambas vazias, zero cobre)
foram removidas da hierarquia e substituídas pelos 4 sheets 04a–d abaixo. Root
`openems_v1.kicad_sch` passou de A4 para **A3** (13 sheets já não cabiam sem sobrepor
o cartão de título).

| Sheet | Ficheiro | Função | Doc | Estado |
|---|---|---|---|---|
| 01 | `01_power` | Protecção VBAT (P-FET, fusível, TVS, bulk) + star GND | `01_power.md` ✅ | ✅ sheet 2026-08-08 (ERC 0, F1/Q1/R1/R2/D1/C1/C2) |
| 02 | `02_ckp` | CKP Hall → `PA0` (espelho do CMP) | `02_ckp.md` ✅ | ✅ sheet 2026-08-08 (ERC 0) |
| 03 | `03_cmp` | CMP Hall → `PA1` | `03_cmp.md` ✅ | ⚠️ rascunho (alinhado ao CKP) |
| 04a | `04_pmic_tps65381` | TPS65381A-Q1 (rails, SPI, WD, ENDRV) | *a escrever* | ❌ sheet só com título — falta símbolo |
| 04b | `04_drive_mc33810` | MC33810 INJ/IGN | *a escrever* | ❌ sheet só com título — falta símbolo |
| 04c | `04_bridge_l9960t` | L9960T ETB+EWG (substitui `06_etb`) | *a escrever* | ❌ sheet só com título — falta símbolo |
| 04d | `04_wbo2_cj125` | CJ125 + heater | *a escrever* | ❌ sheet só com título — falta símbolo |
| 05 | `05_analog` | ADC conforme **pinout_v2** (13 ch) | `05_analog.md` ✅ | ✅ sheet 2026-08-08, ERC 0, netlist 13/13 |
| 07 | `07_flex` | Flex → **`PB4`** (pinout_v2) | `07_flex.md` ✅ pino | ⚠️ rascunho (pino corrigido) |
| 08 | `08_usb` | USB isolado | `08_usb.md` | ❌ vazio |
| 09 | `09_connectors` | AMPSEAL J1/J2 mapa de pinos | `09_connectors_weact.md` | ❌ vazio |
| 10 | `10_knock_dnp` | Knock DNP | `10_knock_dnp.md` | ❌ vazio |
| 11 | `11_mcu_h562` | MCU H562VGT6 local | `11_mcu_h562.md` ✅ | ✅ netlist U1 OK (2026-08-08); globals sync PA0/PA1/PB4 |
| 12 | `12_can` (recomendado) | FDCAN1 + ESD | *a escrever* | ❌ |

Docs de bloco: [`docs/hw/schematic/`](../../docs/hw/schematic/).

### Sheet 11 (MCU) — o que já está fechado no papel

- Pinos verificados contra o symbol oficial; VCAP 2×2,2 µF (WeAct H562 real).
- HSE: `3225-8.00-10-10-10/A` (CL 10 pF), Cload 12 pF/12 pF C0G.
- Sheet desenhada (U1 + decoupling + cristal + BOOT0 + SWD + Y2 DNP).
- ERC sheet isolado: 1 erro agregado de pinos GPIO por ligar (esperado).

### ✅ Netlist U1 corrigido (2026-08-08)

**Causa:** em `lib_symbols` o símbolo estava como `"STM32H562VGTx"` mas a instância
tinha `lib_id "STM32H562VGTx:STM32H562VGTx"` — o KiCad não resolvia os pinos
(`Net-(U1-Pad??)`, 100 pinos na mesma net).

**Fix:** `lib_id` da instância U1 → `"STM32H562VGTx"` (bate com o nome embutido).

**Validado no netlist de projecto:**
- `MCU.PA0` → U1/23 + R13/C2 (sheet 02_ckp)
- `MCU.PA1` → U1/24 + R4/C1 (sheet 03_cmp)
- `MCU.PB4` → U1/90 + flex (sheet 07)

Globals `MCU.PA0` / `PA1` / `PB4` colocados na sheet 11. GPIO ainda sem sheet destino
aparecem como `unconnected-(U1-…)` no netlist — esperado até as outras sheets.

## Convenções de nets (esquemático)

- Rails: `+3V3`, `+5V_SENS_A`, `+5V_SENS_B`, `VBAT`, `VDDA`, `PGND`, `SGND`, `AGND`
- MCU inter-sheet: global labels `MCU.<PORTn>` (ex. `MCU.PA1`)
- Conector: `J1.*` / `J2.*`
- Locais de sheet: labels locais `N_*`
- **Um** `PWR_FLAG` por rail, na sheet que **produz** o rail (PMIC / `01_power`)
- Root = índice de sheets; **não** hierarchical pins nesta fase

Autoridade de pinos: **só** [`pinout_v2.md`](../../docs/hw/pinout_v2.md).

## Netclasses (partida — fase PCB)

| Classe | Trace | Clearance | Nota |
|---|---|---|---|
| `Default` | 0,25 mm | 0,20 mm | lógica, SPI, GPIO |
| `Power` | 1,00 mm | 0,35 mm | VBAT, rails |
| `Injector` | 0,80 mm | 0,30 mm | ⚠️ MC33810 4,5 A — rever IPC-2152 no layout |
| `CKP_VR` | 0,25 mm | 0,40 mm | ⚠️ nome legacy; CKP=Hall — provavelmente fundir com Default |
| `CAN` | 0,25 mm | 0,25 mm | par diferencial |
| `Analog` | 0,25 mm | 0,30 mm | divisores ADC |

## Libs

| Lib | Uso v2 |
|---|---|
| `MCU_ST_STM32H5` (KiCad stock) + `lib/STM32H562VGTx.kicad_sym` | MCU |
| `pesd1can.kicad_sym` | ESD CAN |
| `rusefi_ref.pretty` | AMPSEAL 35 (+ net-tie) |
| `tle8888qk.kicad_sym` | ⛔ referência só — TLE saiu |
| TPS65381A / MC33810 / L9960T / CJ125 | ❌ **a criar** a partir de datasheet, um CI de cada vez |

Footprint AMPSEAL 23: desenhar na **fase PCB** a partir de
[`docs/hw/TE_770669_header_RA_23.pdf`](../../docs/hw/TE_770669_header_RA_23.pdf).

## Ordem de trabalho (esquemático)

Regra §1b de [`docs/hw/README.md`](../../docs/hw/README.md) em **todo** o bloco:
consultar Speeduino/rusEFI; registar adoptamos / adaptamos / rejeitamos.

1. ~~Doc + cristal + desenho inicial `11_mcu_h562`~~ ✅ (limpeza ERC ainda aberta)
2. ~~Limpar sheet 11~~ ✅ (netlist U1 corrigido 2026-08-08)
3. ~~CKP/CMP Hall~~ ✅ `02_ckp` ERC 0; `03_cmp` alinhado
4. ~~Flex em `PB4`~~ ✅ pino corrigido
5. ~~Refazer `05_analog`~~ ✅ ERC 0, netlist 13/13 (2026-08-08)
6. ~~Hierarquia root v2~~ ✅ `04_tle8888_hub`/`06_etb` substituídos por 04a–d (2026-08-08, root A3)
7. ~~`01_power`~~ ✅ desenhada 2026-08-08 (ERC 0: F1/Q1/R1/R2/D1/C1/C2, star GND flags). **Falta ainda:** símbolo + sheet PMIC (`04_pmic_tps65381`)
8. **MC33810 → L9960T → CJ125 → CAN → USB → conectores → knock DNP**
9. ERC projecto completo + PDF + BOM schematic-level
10. **Só depois:** fase PCB (footprints em falta, placement, pours, DRC)

## O que **não** fazer nesta fase

- Não copiar cobre de `../openems_ecu/`
- Não montar WeAct na ECU de motor (só bancada de firmware)
- Não tratar netclasses como fechadas
- Não inventar pinos/símbolos de CI de memória — datasheet + §1
- Não abrir layout/copper até o DoD do esquemático
- Não misturar experimentação tscircuit (raiz do repo) com este projecto KiCad

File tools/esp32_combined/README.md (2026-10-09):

# OpenEMS ESP32 Combined — CKP Generator + Scope + Ardu-Stim Features

Gerador de sinais CKP/CMP (60-2) para bancada HIL do OpenEMS, com scope lógico
de 10 canais e funcionalidades Ardu-Stim integradas.

## Hardware

- **ESP32** (qualquer variante: ESP32, ESP32-S3, ESP32-C3, etc.)
- **RMT hardware** para CKP (GPIO2) e CMP (GPIO4) — jitter ~zero, CPU load ~zero
- **LEDC PWM** para sensores analógicos (MAP, TPS, CLT, IAT, etc.)
- **Wire loopback** GPIO2→GPIO34 para captura CKP no scope

## Ligações ao STM32H562

| ESP32 GPIO | STM32 | Função |
|---|---|---|
| GPIO 2 → | PA0 | CKP output (60-2, RMT) |
| GPIO 4 → | PA1 | CMP output (1 pulso/720°, RMT) |
| GPIO 2 → | GPIO34 | Loopback interno p/ scope CKP |
| GPIO 32 ← | PE9 | IGN1 |
| GPIO 33 ← | PE11 | IGN2 |
| GPIO 26 → | PA3 | MAP (DAC2) — IGN4 (PE15) sem entrada livre |
| GPIO 25 → | PA4 | TPS (DAC1) — IGN3 (PE13) sem entrada livre |
| GPIO 27 ← | PE0 | INJ1 |
| GPIO 14 ← | PE2 | INJ2 |
| GPIO 12 ← | PE4 | INJ3 |
| GPIO 13 ← | PE6 | INJ4 |
| GND — | GND | Obrigatório |

Pinos STM32 = mapa `BOARD=vgt6` (`src/hal/out_pins.h`). Para `BOARD=rgt6`:
INJ1-4 = PA15/PB3/PC10/PC11, IGN1-4 = PC6/PC7/PC8/PC9.

## Funcionalidades

### CKP Generator (Ardu-Stim Features)
- **Geração RMT 60-2**: CKP (58 dentes + gap) + CMP (1 pulso por 720°)
- **Modos RPM**: FIXED, SWEEP (varrimento linear entre RPMs), POT (potenciómetro no ADC)
- **Compressão**: modulação senoidal de RPM em baixas rotações (simula tranco de arranque)
- **Inversão de polaridade**: CKP e/ou CMP invertidos via comando
- **Persistência NVS**: config guardada entre power cycles
- **Presets**: IDLE, CRANK, CRUISE, WOT, COAST (RPM + sensores)
- **Protocolo binário Ardu-Stim**: compatível com GUI Electron original

### Scope Lógico (10 canais)
- IGN1-4, INJ1-4, CKP (loopback), CMP (virtual)
- Modos: LIVE table, EDGE log, PULSE log, WAVE bar
- Timing analysis 720°: sequência de ignição, ângulo de avanço, spacing

## Protocolo Serial

### Texto (115200 baud, compatível hil_test.py)
```
RPM <n>            Define RPM
+ / -              RPM ± 100
0-9                Presets
MODE FIXED         RPM fixo
MODE SWEEP <l> <h> <u>  Varrimento linear
MODE POT           Potenciómetro
COMPRESS ON/OFF    Compressão
INVERT CRANK/CAM   Inverter polaridade
STATUS             Estado completo
SAVE               Guardar em NVS
IDLE/CRANK/...     Presets
MAP/TPS/CLT/IAT    Sensores
l/e/p/w/t/s/r/?    Scope commands
```

### Binário (Ardu-Stim compatível, usado pela GUI Electron)
Comandos: `c` `C` `L` `n` `N` `p` `P` `R` `r` `s` `S` `X`

## Controlo via WiFi

O ESP32 liga-se à tua rede WiFi (modo Station) e expõe uma página web com
sliders para RPM, MAP e TPS — acessível de qualquer browser (telemóvel, PC)
na mesma rede.

1. Cria credenciais locais (nunca commitadas):
   ```bash
   cp wifi_credentials.example.h wifi_credentials.h
   # edita WIFI_SSID / WIFI_PASS
   ln -sf ../wifi_credentials.h src/wifi_credentials.h   # se usares PlatformIO src/
   ```
2. Após o boot, a porta série (115200 baud) imprime o IP atribuído, ex:
   `[WIFI] Ligado! IP: 192.168.1.42`
3. Abre `http://<IP>/` no browser — sliders para RPM (50–9000), MAP (0–300 kPa)
   e TPS (0–100%), com leitura em tempo real.

Endpoints HTTP (também usáveis via curl/script):
```
GET /              Página com sliders
GET /set?rpm=2500  Define RPM (também aceita map=, tps=, combináveis)
GET /status         {"rpm":...,"map":...,"tps":...} em JSON
```

O WiFi corre em paralelo ao protocolo série — ambos podem ser usados ao
mesmo tempo. Se a ligação WiFi falhar (timeout de 15s), o firmware continua
normalmente apenas por série.

## Build

### PlatformIO
```bash
cd tools/esp32_combined
pio run -e esp32dev          # Build
pio run -e esp32dev -t upload  # Upload
pio device monitor -b 115200   # Monitor
```

### Arduino IDE
Abrir `esp32_combined.ino` como sketch normal. As dependências (Preferences.h, rmt_tx.h, ledc.h) fazem parte do core ESP32 Arduino.

## GUI Electron

A app-source em `ardustim_gui/` (main.js, package.json, …) pode estar no tree.
**Binários avrdude, FontAwesome e `package-lock.json` não são versionados**
(regenera com `npm install`; avrdude/esptool vêm do teu PATH ou de um clone local).

```bash
cd tools/esp32_combined/ardustim_gui
npm install
pip install esptool    # necessário para firmware upload
npm start
```

A GUI comunica via protocolo binário Ardu-Stim. Necessita `esptool.py` no PATH para
upload de firmware para o ESP32.

## Ficheiros

| Ficheiro | Descrição |
|---|---|
| `esp32_combined.ino` | Firmware principal (sketch único) |
| `web_page.h` | Página HTML/JS de controlo WiFi (RPM/MAP/TPS) |
| `wifi_credentials.example.h` | Template WiFi — copiar para `wifi_credentials.h` |
| `platformio.ini` | Build config PlatformIO |
| `ardustim_gui/` | GUI Electron (sources; vendor bins/fonts ignorados) |

## Test HIL

```bash
cd tools/hil_test
python hil_test.py --mode regression   # Regressão (texto serial)
python hil_test.py --mode timing       # Timing analysis 720°
```

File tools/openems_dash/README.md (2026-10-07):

# OpenEMS Calibration Cockpit

Dashboard web de telemetria e calibração em tempo real para a ECU OpenEMS
(STM32H562, USB CDC). Frontend redesenhado: cockpit escuro denso, navegação
por grupos (Tables / Maps / Engine / Diag), helpers puras testáveis.

## Requisitos

Debian/Ubuntu bloqueia `pip install` no Python do sistema (PEP 668).
Use um **venv** local (recomendado):

```bash
cd tools/openems_dash
python3 -m venv .venv
source .venv/bin/activate
pip install -r requirements.txt
```

Alternativas:

```bash
# pacotes Debian (sem venv)
sudo apt install python3-fastapi python3-uvicorn python3-serial python3-websockets

# ou override (não recomendado)
pip install --break-system-packages fastapi "uvicorn[standard]" pyserial
```

## Uso

```bash
cd tools/openems_dash
source .venv/bin/activate          # se usou venv
python server.py                   # auto-detecta /dev/ttyACM*
python server.py --port /dev/ttyACM0 --http-port 8000 --rate 30
```

Abrir <http://localhost:8000>. Primeira instalação: aba **Install** (guia em
7 passos: motor, polaridade CKP/CMP, dead time, teste de saídas, offset do
trigger, lâmpada de ponto, gravar; mais exportar/importar tune e restaurar
padrões de fábrica).

Sem o extra `[standard]` do uvicorn não há WebSocket e a telemetria fica
parada (404 em `/ws/telemetry`).

Sem activar o venv:

```bash
./.venv/bin/python server.py
```

## Funcionalidades

- **Status bar** ~30 Hz: gauges primários (RPM, MAP, TPS, λ, λtgt, PW, Ign, CLT)
  + chips SYNC / SEQ / LIMP / WBO2 / REV / FAULT / TC / BENCH.
- **Bench-mode** (sidebar): comando `B` — CLT=90°C, IAT=25°C, λ=1.000 simulados
  e timeouts CKP relaxados para HIL (sem sondas / WBO2).
- **Telemetria**: gauges secundários, strip-charts 60 s (uPlot),
  osciloscópio CKP/CMP, diagnóstico de loop.
- **Editores de tabela** VE (pág. 1), Spark (pág. 2), Lambda target (pág. 4):
  grid 20×20 com heatmap, eixos RPM×MAP, Trace vs Manual, auto-write RAM.
  - *Read* → relê a página da ECU (RAM)
  - *Write* → escreve pendentes na RAM (edições já vão ao teclar)
  - *Save* → grava flash (`b`); badge “não gravado em flash”
- **Atalhos (grelha, modo Manual):**
  - `A` / `Z` (ou `+`/`-`) — step nas células seleccionadas
  - `H` / `V` — interpolação linear horizontal/vertical
  - `X` — undo da última operação
  - Setas / Shift+setas / arraste — navegação e selecção
- **Maps**: Pedal (pág. 8), Boost (pág. 9), Learn/LTFT (pág. 12).
- **Parâmetros** (págs. 0/5/6/7): correções 1D, dead time, dwell, AE, X-Tau,
  crank, CAN RX — formulário com filtro, Write/Save.
- **Output tests**: injectors/coils/ETB/EWG (motor parado).
- **Datalog** CSV em `logs/` com todos os campos do realtime.

## Arquitetura

- `protocol.py` — protocolo serial (mestre-único); codecs das páginas.
- `server.py` — FastAPI; thread serial poll `A` @ 30 Hz; WS `/ws/telemetry` + REST.
- `static/` — frontend sem build step:
  - `index.html` + `style.css` — shell / design system
  - `js/helpers.js` — helpers puras (heatmap, axis, clamp, format)
  - `app.js` — telemetria, grelhas, params, maps, output tests
  - `uplot.min.*` — charts vendorizados

## Sem placa: ECU simulada

O firmware real (parser do protocolo, páginas, burn) roda no PC sobre um
pseudo-terminal; o motor fica parado (calibração, burn e teste de saídas).

```bash
make sim-ecu NVM=/tmp/openems_nvm.bin     # imprime: OpenEMS sim ECU on /dev/pts/N
python server.py --port /dev/pts/N        # noutro terminal
```

O ficheiro `NVM` guarda o que for gravado (Burn) entre reinícios.

## Testes

```bash
make dash-check DASH_PY=.venv/bin/python   # helpers JS + protocolo vs ECU simulada
node --test tests/helpers.test.js          # só os helpers
```

> A página 7 (dwell 2D) requer firmware com o fix de acesso à página 7
> (`ui_protocol.cpp`) — ver commit correspondente.

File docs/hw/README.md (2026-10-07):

# Hardware — placa de interface OpenEMS v1

Ponto de entrada da documentação de hardware. **Ler esta página antes de qualquer outra.**

**Objetivo do projeto:** sair da bancada para a **primeira partida em motor real** (4 cilindros, roda
60-2, injeção e ignição sequenciais, borboleta eletrónica).

**Desenho KiCad de produção:** projecto **em branco** → `hardware/openems_v1/`  
(MCU **H562 soldado** LQFP100, **4 camadas**, arquitectura v2 — CIs dedicados,
TLE8888 **saiu**, ver [`architecture_v2.md`](architecture_v2.md)).  
WeAct H562 = **só bancada de firmware**, não entra na PCB de produção.

⛔ **O fork do microRusEFI deixou de ser a base de desenho (2026-08-07).** O mRE continua
no repo como **referência** (`hardware/vendor/hw_microRusEfi`) — é a implementação que a
regra §1b obriga a consultar antes de cada bloco. O board antigo `hardware/openems_ecu/`
**não foi apagado**, mas não recebe mais trabalho. Porquê da mudança:
[`microruseefi_as_base.md`](microruseefi_as_base.md). Hellen-One **não** é a base da ECU.

---

## 1. Mapa de autoridade — qual fonte manda sobre o quê

⚠️ **Esta tabela é o antídoto para a causa-raiz dos dois piores incidentes do projeto:** o driver do
TLE8888 foi escrito contra um mapa de registadores **inventado**, herdado da narrativa do
`wiring_diagram.md`; e uma tabela stale mandava remover o pull-down do `PA0`, o que teria desfeito o fix
de falso-sync. **Ambos vieram de autoridade duplicada que se dessincronizou.**

| Assunto | Fonte de verdade | ⚠️ NÃO usar |
|---|---|---|
| Mapa de pinos RGT6 vs VGT6 | `pinout.md` | `../wiring_diagram.md` |
| INJ/IGN, enables, BSRR | `src/hal/out_pins.h` | qualquer doc |
| Canais e pinos de ADC | `src/hal/adc.h` | qualquer doc |
| Registadores do TLE8888 | `src/hal/tle8888_regs.h` | qualquer doc |
| Arquitetura, blocos, BOM, **decisões e porquês** | `interface_board_v1.md` | — |
| Alimentação, condicionamento, atuadores, conector, terra | [`../wiring_diagram.md`](../wiring_diagram.md) | — |
| **Números de pino e AF do MCU (v2)** | [`pinout_v2.md`](pinout_v2.md) | inventar/copiar de spec externa |
| **Arquitectura v2 (MC33810/L9960T/TPS65381A/CJ125)** | [`architecture_v2.md`](architecture_v2.md) | — |
| ~~Ligações pino-a-pino (netlist)~~ | `netlist_v1.md` | ⚠️ **pré-v2** — blocos do TLE8888 anulados |
| Contraprova do mapa TLE8888 | `tle8888_crosscheck.md` | — |
| **Pinos de package LQFP-100 do TLE8888** | `tle8888_pinout.md` | inventar números |
| Registadores/periféricos do MCU | `stm32h562_ref.md` | — |
| **Forma / furos / headers do coreboard WeAct VGT6** | `weact_h562_coreboard.md` | assumir board 64 pinos |
| **Esquemático WeAct V1.0 (P1/P2 nets)** | `weact_h562_schematic.md` + `weact_h562_v10_schdoc.pdf` | — |
| **AMPSEAL 35/23 plugues + headers PCB** | `ampseal_connectors.md` + PDFs TE | inventar footprint |
| **KiCad libs Speeduino/rusEFI (review)** | `kicad_vendor_review.md` | inventar footprint se já existe upstream |
| **BOM candidatos** | `bom_v1_candidates.md` | — |
| **Esquemático modular (sheets)** | `schematic/README.md` | um PDF monólito sem revisão |
| **Board de produção (KiCad em branco)** | `hardware/openems_v1/` | `hardware/openems_ecu/` (fork mRE, congelado) |
| ~~Base de desenho a partir do mRE~~ | `microruseefi_as_base.md` | **supersedido** — mRE é referência, não cobre |
| ~~H562 no cobre microRusEFI (bring-up)~~ | ~~`pinout_mre_bringup.md`~~ | **removido** com o `BOARD=mre` |
| ~~Condicionamento VR discreto~~ | `vr_input_conditioning.md` | **supersedido** (MAX9926/9924 saiu) |

### A regra
**O "porquê" vive num sítio só. Nenhum documento repete o racional de outro.**
`netlist_v1.md` diz *o que liga a quê* e aponta para os blocos; não explica escolhas.
Código sempre ganha a documento. Se divergirem, o documento está errado.

---

## 1b. ⭐ Antes de desenhar qualquer bloco — consultar Speeduino e rusEFI

**Regra geral (obrigatória):** antes de elaborar um esquemático **do zero** para cada
módulo (alimentação, VR/CKP, injectores, ignição, ETB, CAN, USB, knock, VVT, relés,
conector, terra, …), **consultar primeiro** as implementações e o hardware de
referência do **Speeduino** e do **rusEFI**. Só depois adaptar ao OpenEMS
(STM32H562 VGT6 + TLE8888-2QK + contratos do firmware).

Isto não é “copiar a placa”; é **não reinventar armadilhas** que a comunidade já
pagou: pinout de CI, ordem de init SPI, polaridade, pull, clamp, direct-drive,
layout de potência vs sync, fusíveis, terra.

| O quê procurar | Speeduino | rusEFI |
|---|---|---|
| Esquemáticos / boards | `reference/`, hardware boards no repo/wiki | `hardware/`, schematics, board packages |
| Drivers de estágio / CI | `speeduino/` (ex. MC33810, injectors) | `firmware/hw_layer/drivers/` (ex. `gpio/tle8888.cpp`) |
| Condicionamento VR/Hall | wiki + boards | wiki + `hw_layer` + forum |
| Knock / WBO2 / CAN | community boards | wiki + drivers |

**Cópias locais neste ambiente (usar se existirem; senão upstream):**
- Speeduino: `~/Downloads/speeduino-202501.6/speeduino` e `~/Arduino/speeduino`
- rusEFI (firmware/hw): `~/RusefiH5/.work/rusefi` (e projectos em `~/RusefiH5/`)
- Upstream: [speeduino/speeduino](https://github.com/speeduino/speeduino),
  [rusefi/rusefi](https://github.com/rusefi/rusefi)

**Checklist por módulo (antes do KiCad / netlist final):**
1. Achar **pelo menos uma** implementação de referência (board ou driver) no Speeduino **ou** rusEFI.
2. Anotar o que **adoptamos**, o que **adaptamos** (H562 / TLE8888 / pinout nosso) e o que **rejeitamos** (e porquê).
3. Preferir contraprova independente (como `tle8888_crosscheck.md`) a inventar mapa/pinout a partir de memória ou de doc stale.
4. Se o módulo for só footprint (ex. knock v2), registar a referência na netlist mesmo assim.

⚠️ **Não substitui datasheet.** Speeduino/rusEFI validam *uso no mundo real*; o datasheet
valida *limites eléctricos*. Os dois em conjunto.

Memória de projecto: `always-check-speeduino-rusefi-ms` (já invocada no plano de knock).

---

## 2. Registo de decisões

Todas fechadas em **2026-07-20**, na branch `feat/interface-board-v1`, salvo indicação em
contrário. Fundamentação em `interface_board_v1.md` salvo indicação em contrário. A coluna
**Estado v2** regista o que a arquitectura de CIs dedicados (2026-08-07,
[`architecture_v2.md`](architecture_v2.md)) fez a cada uma — ⛔ **anulada**, 🔄 **mudou**
(o conceito sobrevive, o detalhe não — ver `pinout_v2.md`), ✅ **sobrevive** sem alteração.
Não repetir aqui o racional da troca — vive só em `architecture_v2.md`.

| Decisão | Porquê, em uma frase | Commit | Estado v2 |
|---|---|---|---|
| **Alvo VGT6 (LQFP100)** | GPIOE inteiro para INJ/IGN, sem os conflitos do RGT6 | — | ✅ sobrevive |
| ~~TLE8888-2QK como hub de potência~~ | Substitui FETs, drivers de bobina, relés, transceiver CAN e reguladores de 5 V; a **-2QK** tem watchdog desativado de fábrica, e errar o watchdog mata o motor no bring-up | `a5f95fb` | ⛔ anulada — CIs dedicados |
| **INJ/IGN por direct drive** | `IN1–IN8` são ativo-alto com pull-down interno → **scheduler congelado fica intacto** | `a5f95fb` | 🔄 mudou — mesmo princípio, agora via MC33810 (entradas paralelas directas, mesmos pinos GPIOE) |
| ~~Driver TLE8888 reescrito~~ | Mapa inventado + frame invertido; agora unlock + InConfig + OE_SET (rusEFI-aligned). **Ainda sem clock em silício** | `a5f95fb` + hub fix | ⛔ anulada — `tle8888.cpp`/`tle8888_regs.h` reformam-se (dívida de firmware, não escrito) |
| ~~INJEN=`PE14` / IGNEN=`PE3`~~ | Corte de injeção e ignição em hardware, independente do SPI *e* do escalonador. `PE14` porque o LQFP100 do H562VGTx não bonda `PE1` | `380a0c5` + fix PE1→PE14 | ⛔ anulada — MC33810 usa `EN`(`PD11`)/`RSTB`(`PD10`)/`FAULTB`(`PD9`), um enable só, não INJ/IGN separados. `PE14` e `PE3` foram reciclados (`MAIN_RELAY` e `TPS65381_ENDRV`) |
| **Bomba/ventoinha** | Em `PB12`/`PB13` matavam o `SPI2_SCK` no boot | `380a0c5` | 🔄 mudou — razão mantém-se (SPI2 continua em `PB12-15` para PMIC/MC33810/L9960T/CJ125), mas o pino mudou: `PE10`/`PE12` agora são VVT1/VVT2; bomba/ventoinha foram para `PE7`/`PE8` |
| **SDMMC guardado no RGT6** | `PC8` é IGN3 no RGT6; ligar o datalog reconfiguraria o pino de uma bobina | `380a0c5` | ✅ sobrevive — não depende do hub |
| ~~CKP pela interface VR do TLE8888~~ | Zero-crossing com armamento por pico, clamp e diagnóstico integrados → **MAX9924 sai da BOM** | — | ⛔ anulada — sem TLE8888 não há interface VR; **CKP passa a Hall** |
| **CMP: Hall** direto ao `PA1` | ~~O CI tem **um** canal VR, gasto no CKP~~ | — | 🔄 mudou — pino e sensor sobrevivem, mas a razão morreu com o TLE (não há mais canal VR a partilhar). Motivo actual: CKP **também** é Hall, decisão irmã em `architecture_v2.md` |
| **VBATT em `PC3`/INP13** | Antes era fixado em 12000 mV, o que subestimava dead-time e encurtava o dwell no cranking | `34b40e3` | ✅ sobrevive |
| ~~EWG diferido para v2~~ | Turbo-específico; é o que liberta `PC3` para o VBATT | `34b40e3`, `8c3d282` | ⛔ anulada — **populado na v2**, no L9960T junto com o ETB. (O "v2" aqui era genérico, revisão futura — coincide, mas não é a arquitectura v2 de CIs dedicados) |
| **Knock diferido** | Bloco analógico mais difícil, não contribui para a primeira partida, e o retard **mascara problema mecânico** | — | ✅ sobrevive — continua diferido, sem relação com a troca de CIs. (Mesmo aviso: "v2" no nome original é genérico, não a arquitectura de CIs dedicados) |
| ~~ETB: BTS7960 @ 10 kHz~~ | A 20 kHz sobravam 20% de margem; o DRV8701 não é drop-in (firmware é 3 pinos, ele é 2) e transferia o layout de potência. Path real: `etb_driver_init` → `etb_pwm_init(10000)` | `11c39f4` + fix path | ⛔ anulada — **L9960T substitui o BTS7960**, ETB e EWG na mesma ponte dupla. A rejeição do DRV8701 por ser de 2 pinos foi explicitamente revertida: o L9960T é igualmente PWM+DIR e foi aceite. `etb_driver.cpp` **reescreve-se** de 3 pinos para 2+SPI (dívida de firmware) |
| **VREF+ = VDDA 3,3 V filtrado**, (c) DNP | Os trims absorvem **deriva** mas não **ruído** → o esforço rende no LDO e no layout, não numa referência exata | `8df4dbc` | ✅ sobrevive |
| **Conector: AMPSEAL `776164-1` (35, sinais) + `770680-1` (23, potência)** | Tamanhos diferentes são **impossíveis de trocar**; potência de bobinas/injetores **não atravessa a ECU** | `fd9faa0` | ✅ sobrevive |
| **Montagem na cabine**, não no compartimento do motor | O coreboard é grau consumidor — nenhuma caixa resolve ciclo térmico; e põe a antepara aterrada entre a ECU e a ignição | `fd9faa0` | ✅ sobrevive |
| **VVT: montar dois, comissionar um** | Os dois PIDs partilham o `pos_deg_x10` do único CMP | `43a2ff0` | ✅ sobrevive — `PE10`/`PE12` no pinout v2 |
| ~~Fingerprint de reset values~~ | `write_verify` é cego ao endereço errado-mas-válido | `43a2ff0`, `529b1ec` | ⛔ anulada — era técnica específica do TLE8888. Os CIs novos têm os seus próprios sinais de diagnóstico (`MC33810_FAULTB`, `TPS65381A` via SPI) mas **não têm equivalente ao fingerprint desenhado ainda** — dívida de firmware, não só de hardware |
| **KiCad, 4 camadas** | Mínimo honesto para os pours PGND/SGND/AGND separados | — | ✅ sobrevive |
| **USB com isolador galvânico** | Laço de terra com o portátil é matador clássico de ECU | — | ✅ sobrevive |
| **Corte da bomba 3 s → 2 s** | Corta mais cedo num acidente sem cortar num calo momentâneo | `380a0c5` | ✅ sobrevive — lógica de firmware, independente do pino físico |

---

## 3. Em aberto

| Item | Estado |
|---|---|
| **Part numbers Tier C finais** | Candidatos em `bom_v1_candidates.md` — fechar stock/preço. |
| **Bobinas** | IGN = gate IGBT 20 mA — escolher bobina/IGBT **antes** de chicote. |
| **Caixa / coating / orçamento** | Aresta conector ≥ **125 mm** (dois AMPSEAL RA); alvo de custo. |

**Já no código (bring-up ainda sem silício):**
- Driver hub: unlock / InConfig / OE_SET / DD pump-fan
- Eco de endereço SPI (gate) + fingerprint consultivo (só OpConfig0/OutConfig3)
- page0 56–76 restaurado no boot (`apply_page0_trims_driveability`)
- **Polaridade CKP/CMP** page0[258] + `tim5_ic_set_capture_polarity` (Speeduino: TrigEdge; pull segue a borda)

**Relé principal — ✅ decisão v1 (após rusEFI):** ECU alimentada por **key-on** (sem power-latch MCU).
Via `MAIN_RLY` no AMPSEAL fica **reservada / DNP** para o driver de main-relay do TLE
(`Cmd0` MRON/MRSE no rusEFI). Não comandar na v1 — evita matar flash a meio de burn.

---

## 4. ⚠️ Afirmado nos documentos mas **NÃO verificado**

A secção mais importante desta página. Tudo aqui está escrito algures como se fosse facto, e **não** foi
confirmado contra fonte primária. Não construir em cima sem confirmar.

| Afirmação | Estado real |
|---|---|
| **Mapa de registadores do TLE8888** | ✅ **Endereços confirmados** por implementação independente (rusEFI) — ver `tle8888_crosscheck.md`. ⚠️ Mas **nenhum valor de reset** foi confirmado, e 5 dos 7 do fingerprint usam endereços que o rusEFI não toca. |
| **Atraso de propagação do VR** | 🚨 **O datasheet NÃO especifica.** Os 50 ns que os docs citavam eram do **MAX9924**, peça que saiu da BOM. Medição obrigatória no passo 3. |
| **VREF+ é pino separado no LQFP100** | ✅ **Sim** no H562 LQFP100 (`stm32h562vg.pdf` pinout — VREF+ ≠ double-bond VDDA). Opção (a): VREF+→VDDA filtrado. |
| **Números de pino do TLE8888** | ✅ **Verificados** DS Rev 1.2 §3 + rusEFI lib — `tle8888_pinout.md`. |
| **Dimensões do coreboard** | ✅ **WeAct V1.0 Board Shape:** 38,62 × 69,10 mm, furos Φ3,2 @ 2,80 mm — `weact_h562_coreboard.md`. Altura USB ainda a medir. |
| **Todo o driver TLE8888** | 🚨 **Nunca clockou silício.** Os 1234 host-tests mockam o SPI. Só o bring-up decide. |

---

## 5. Antes do layout — medições

### Coreboard WeAct (VGT6) — ✅ shape fechado
Ver **`weact_h562_coreboard.md`** (PDF *Board Shape 外形* V1.0):
- Contorno **38,62 × 69,10 mm**
- Furos **Φ 3,2**, offset **2,80 mm**, pitch horizontal **30,48 mm**
- Headers laterais dual-row **2,54 mm**, GPIOE exposto

**Ainda a medir na peça física:** altura total (USB-C + headers + componentes);
confirmar pin 1 de cada conector face ao silkscreen.

### AMPSEAL — plugues + headers PCB ✅
Ver **`ampseal_connectors.md`**:
- Plugs: `776164-1` (35) / `770680-1` (23)
- Headers RA (recomendado cabine): **`1-776180-1`** (35 gold) + **`1-770669-1`** (23 gold)
- Drawings no repo: `TE_776180_*.pdf`, `TE_770669_*.pdf`, `TE_776230_*.pdf` (vertical alt.)
- Aresta mínima ≈ **125 mm**; altura header RA ≈ **18 mm** + plug

---

## 6. Sequência de verificação

Ordem inegociável — **bancada → ETB validado → motor**. Detalhe em `interface_board_v1.md`.
⚠️ **Escrita pré-v2** (2026-07-20); os passos 0 e 3 assumiam o TLE8888/VR e ficaram void
com a arquitectura de CIs dedicados (`architecture_v2.md`, 2026-08-07). A ordem geral
continua válida — bancada antes de ETB, ETB antes de motor.

0. ~~Fingerprint + eco do TLE8888~~ 🚨 **sem substituto desenhado.** O TLE8888 saiu da
   produção; o passo existia porque o `write_verify` do TLE era cego ao endereço
   errado-mas-válido (ver decisão "Fingerprint de reset values" anulada em §2). Os CIs
   novos (MC33810, L9960T, CJ125, TPS65381A) têm os seus próprios sinais de diagnóstico
   (`MC33810_FAULTB`, SPI do TPS65381A) mas **não têm um passo 0 equivalente definido** —
   dívida de firmware/bring-up, não só de hardware. Escrever antes do primeiro power-on
   dos CIs novos.
1. Host tests verdes (`make host-test`, `make host-test-vgt6`).
2. Scope de INJ/IGN e sync CKP/CMP de 200 a 8500 rpm com o estimulador.
3. **Caracterizar o front-end CKP** — 🔄 **reformulado.** CKP deixou de ser VR (era pela
   interface do TLE8888) e passou a **Hall**, mesmo condicionamento do CMP. Já não se mede
   "atraso de propagação do VR" — mede-se o atraso do front-end Hall escolhido, e fecha-se
   a par da polaridade RISING/FALLING pendente (ver `cmp-ckp-capture-edge-polarity` em
   memória) assim que o datasheet do sensor existir.
4. **Ruído sob carga** — o teste que teria apanhado o falso-sync original.
5. Analógicos, VBATT contra multímetro; depois flex e VVT.
6. **Gate do ETB** — autocal e PID com chicote real, **desacoplado do motor**. 🔄
   O driver muda de BTS7960 (3 pinos) para **L9960T** (PWM+DIR+SPI, `etb_driver.cpp` por
   reescrever) — o gate em si não muda de posição na sequência, só o que há para testar.
7. Motor, escalonado: cranking sem faísca → faísca sem combustível → partida.

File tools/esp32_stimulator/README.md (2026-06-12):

# ESP32 Sensor Stimulator — OpenEMS

Gera todos os sinais de **entrada** do STM32H562: roda fônica CKP 60-2, cam CMP,
e 10 canais analógicos de sensor. Permite testar o ECU em bancada sem motor.

---

## Ligações

### Sinais digitais (conexão directa)

| ESP32 GPIO | STM32 | Sinal | Notas |
|---|---|---|---|
| GPIO2 | PA0 | CKP 60-2 | 58 dentes + gap de 2, 3.3 V |
| GPIO4 | PA1 | CMP | 1 pulso por ciclo completo (2 rotações) |
| GND | GND | Referência | **Obrigatório** |

### Sensores analógicos — DAC interno (sem filtro externo)

| ESP32 GPIO | STM32 | Sensor | Tipo |
|---|---|---|---|
| GPIO25 | PA2 (ADC1_IN3) | MAP | DAC1 — analógico verdadeiro 8-bit |
| GPIO26 | PA4 (ADC1_IN5) | TPS legacy | DAC2 — analógico verdadeiro 8-bit |

### Sensores analógicos — LEDC PWM + filtro RC

**Filtro por canal:** série 10 kΩ + 100 nF para GND  
Frequência de corte: fc = 1 / (2π × 10 kΩ × 100 nF) ≈ **159 Hz**  
Atenuação a 39 kHz PWM: ≥ 48 dB — ripple < 0.5 mV

```
ESP32 GPIO ──[10 kΩ]──┬── STM32 ADC pin
                       │
                    [100 nF]
                       │
                      GND
```

| ESP32 GPIO | STM32 | Sensor | Range simulado |
|---|---|---|---|
| GPIO13 | PC2 (ADC2_IN1) | CLT | −40 a +150 °C |
| GPIO12 | PC3 (ADC2_IN2) | IAT | −40 a +150 °C |
| GPIO14 | PB0 (ADC1_IN7) | APP1 | 0–100% |
| GPIO27 | PB1 (ADC1_IN8) | APP2 | 0–100% (espelho APP1) |
| GPIO16 | PC4 (ADC2_IN13) | FUEL_PRESS | 0–5 bar |
| GPIO17 | PC5 (ADC2_IN14) | OIL_PRESS | 0–5 bar |
| GPIO18 | PC0 (ADC1_IN9) | ETB_TPS1 | 0–100% |
| GPIO19 | PC1 (ADC1_IN10) | ETB_TPS2 | 0–100% invertido |

---

## Nota sobre CLT / IAT

Se a PCB do ECU tiver **pull-up** para 3.3 V nos pinos CLT/IAT (circuito NTC típico):

```
3.3V ──[R_pull]──┬── ADC pin
                  │
              [NTC sensor]
                  │
                 GND
```

O pull-up irá **conflituar** com a tensão forçada pelo ESP32.

**Solução A (recomendada):** remover o resistor de pull-up na PCB (DNP) durante
os testes em bancada.

**Solução B:** interpor um buffer rail-to-rail (ex: TLV9001, LM358) entre o GPIO
e o pino ADC, com alimentação 3.3 V.

**Solução C:** se o valor do pull-up for conhecido (ex: R_pull = 2.2 kΩ), calcular
a tensão necessária na saída do ESP32 para compensar — o firmware usa uma tabela
linear, por isso a relação é simples, mas exige calibração manual.

---

## Calibração (mirrors de `sensors.cpp`)

| Sensor | Fórmula raw → valor físico | Inversa (valor → raw) |
|---|---|---|
| MAP | `kPa = raw × 300 / 4095` | `raw = kPa × 4095 / 300` |
| TPS/APP | `pct = (raw − 200) × 100 / 3695` | `raw = 200 + pct × 3695 / 100` |
| CLT/IAT | tabela linear −40..+150 °C, 128 entradas | `raw = ((T×10+400)×127/1900)×32+16` |
| FUEL/OIL | `bar = raw × 2.5 / 4095` | `raw = bar×1000×4095/2500` |

A tabela CLT/IAT usada é a tabela de **teste por defeito** (`init_tables()` em
`sensors.cpp`). Se o firmware for carregado com uma tabela NTC real (Steinhart-Hart),
é necessário recalibrar os valores de temperatura para raw.

---

## Comandos série (115200 baud)

### Parâmetros individuais

```
RPM 1500       → set RPM (50-6000)
MAP 55         → MAP em kPa (0-300)
TPS 20         → TPS em % (0-100)
CLT 90         → temperatura refrigerante °C (-40 a +150)
IAT 35         → temperatura ar admissão °C (-40 a +150)
APP 30         → pedal acelerador % (0-100)
FUEL 35        → pressão combustível bar×10 (35 = 3.5 bar)
OIL 25         → pressão óleo bar×10
ETB 25         → borboleta ETB % (TPS2 = 100-n, anti-phase)
```

### Presets

| Preset | RPM | MAP | TPS | CLT | IAT | APP | FUEL | OIL |
|---|-----|-----|-----|-----|-----|-----|---|-----|
| `IDLE` | 700 | 35 kPa | 3% | 90°C | 25°C | 0% | 3.5 bar | 2.0 bar |
| `CRANK` | 200 | 101 kPa | 0% | 20°C | 15°C | 0% | 2.0 bar | 0.5 bar |
| `CRUISE` | 2000 | 55 kPa | 20% | 90°C | 35°C | 20% | 3.5 bar | 3.0 bar |
| `WOT` | 4000 | 100 kPa | 100% | 90°C | 40°C | 100% | 3.8 bar | 4.0 bar |
| `COAST` | 2000 | 25 kPa | 0% | 90°C | 35°C | 0% | 3.5 bar | 2.5 bar |

### Outros

```
STATUS   → imprimir estado actual + raw ADC + tensão calculada
?        → ajuda
```

---

## Diferença em relação ao `esp32_combined`

| Ferramenta | Função | GPIO25/26 |
|---|---|---|
| `esp32_combined` | CKP gen + scope (monitora saídas ECU) | Entradas: IGN2, IGN3 |
| `esp32_stimulator` | Estimulador (gera entradas para ECU) | Saídas: MAP (DAC1), TPS (DAC2) |

São sketches **mutuamente exclusivos** — usar um segundo ESP32 se se quiser
estimulação + scope simultâneos.

---

## Exemplo de sessão

```
> IDLE
  [STIM] Preset: IDLE

> STATUS
  RPM:       700
  MAP:  PA2   35 kPa   raw= 478  V=0.385 V
  TPS:  PA4    3 %     raw= 311  V=0.250 V
  CLT:  PC2   90 °C   raw=2800  V=2.256 V
  ...

> RPM 1000
  [STIM] RPM=1000

> MAP 45
  [STIM] MAP=45 kPa

> CLT 20
  [STIM] CLT=20°C
```

---

## Dependências Arduino

- ESP32 Arduino Core ≥ 2.0
- `driver/dac.h` (incluído no ESP-IDF ≥ 4.4)
- `driver/ledc.h` (incluído)
- Nenhuma biblioteca externa necessária

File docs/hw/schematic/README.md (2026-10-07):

# Esquemático modular — OpenEMS ECU v2

⚠️ **Arquitectura activa é a v2** (2026-08-07) — TLE8888 saiu; entraram
TPS65381A-Q1 / MC33810 / L9960T / CJ125. Ver [`../architecture_v2.md`](../architecture_v2.md).

## Fase actual — só esquemático profissional

**Faz-se agora:** docs de bloco + sheets KiCad + ERC + PDF/BOM schematic.

**Não se faz agora:** layout, copper, pours, DRC de PCB, gerbers. Footprint AMPSEAL 23
é dívida da **fase PCB**, não bloqueia o mapa eléctrico no esquemático.

Projecto: `hardware/openems_v1/openems_v1.kicad_pro`  
Autoridade de pinos: [`../pinout_v2.md`](../pinout_v2.md)  
Porquê / arquitectura: [`../architecture_v2.md`](../architecture_v2.md)  
Nets pré-v2 (só blocos que sobreviveram): `../netlist_v1.md` — **não** copiar blocos TLE.

## Definition of done (por sheet)

Um sheet só fecha quando cumprir **todos**:

| Critério | Nota |
|---|---|
| Correctness | Pinos/nets batem com `pinout_v2.md` |
| §1b | Doc com Adoptamos / Adaptamos / Rejeitamos (Speeduino/rusEFI ou DS) |
| ERC | 0 erros estruturais no sheet |
| Legibilidade | Fios + junctions; power symbols; globals só inter-sheet |
| Naming | Rails `+3V3`/`+5V_SENS_*`/`VBAT`/`*GND`; `MCU.*`; `J1.*`/`J2.*` |
| Apresentação | `title_block`; valores + PN; DNP marcado |
| Doc sync | Checklist do `.md` + este README actualizados |
| Sem PCB | Não se faz placement/copper |

**DoD do projecto (fase esquemático):** hierarquia v2 desenhada + ERC projecto sem erros
bloqueantes + PDF multi-sheet + BOM schematic. Layout = fase seguinte.

## Convenções

- **Global labels** para nets inter-sheet (`MCU.*`, `J1.*`, rails). Root = índice.
- **Um** `PWR_FLAG` por rail, na sheet que **produz** o rail.
- Não misturar hierarchical pins e globals na mesma net nesta fase.

## Docs de bloco e estado

| Ordem | Sheet alvo | Ficheiro doc | Estado doc | Estado KiCad |
|---:|---|---|---|---|
| 0 | Raiz | este README | ✅ | hierarquia legacy no disco |
| 1 | `01_power` | `01_power.md` | 🔄 stale (ainda fala em TLE/buck) | ❌ vazio |
| 2 | `02_ckp` | `02_ckp.md` | ✅ Hall (espelho CMP) | ✅ sheet 2026-08-08, ERC 0 |
| 3 | `03_cmp` | `03_cmp.md` | ✅ espelho CKP | ⚠️ rascunho (título ok; net MCU bloqueada) |
| 4a | `04_pmic_tps65381` | *a escrever* | ❌ | ❌ + símbolo |
| 4b | `04_drive_mc33810` | *a escrever* | ❌ | ❌ + símbolo |
| 4c | `04_bridge_l9960t` | *a escrever* (substitui `06_etb.md`) | ⚠️ `06_etb.md` stale | ❌ + símbolo |
| 4d | `04_wbo2_cj125` | *a escrever* | ❌ | ❌ + símbolo |
| 5 | `05_analog` | `05_analog.md` | ✅ pinout_v2 13 ch | ✅ sheet 2026-08-08, ERC 0 |
| 7 | `07_flex` | `07_flex.md` | 🔄 pino → **PB4** | ⚠️ rascunho (PB5 errado) |
| 8 | `08_usb` | `08_usb.md` | ✅ esboço | ❌ vazio |
| 9 | `09_connectors` | `09_connectors_weact.md` | ✅ | ❌ vazio |
| 10 | `10_knock_dnp` | `10_knock_dnp.md` | ✅ | ❌ vazio |
| 11 | `11_mcu_h562` | `11_mcu_h562.md` | ✅ | 🔄 limpeza ERC |
| 12 | `12_can` | *a escrever* | ❌ | ❌ |

Docs anulados / stale a não seguir:

- `04_tle8888_hub.md` — ⛔ anulado (TLE saiu)
- `06_etb.md` — ⚠️ stale (BTS7960); conteúdo migra para `04_bridge_l9960t`
- `02_ckp.md` — ⚠️ até ser reescrito como Hall

## Hierarquia KiCad (alvo)

```
openems_v1.kicad_sch                      (root — índice)
├── sheets/01_power.kicad_sch
├── sheets/02_ckp.kicad_sch               ← ✅ Hall, espelho CMP (2026-08-08)
├── sheets/03_cmp.kicad_sch               ← ⚠️ rascunho
├── sheets/04_pmic_tps65381.kicad_sch     ← substitui parte de 01 + hub
├── sheets/04_drive_mc33810.kicad_sch
├── sheets/04_bridge_l9960t.kicad_sch     ← substitui 06_etb
├── sheets/04_wbo2_cj125.kicad_sch
├── sheets/05_analog.kicad_sch            ← pinout_v2 only
├── sheets/07_flex.kicad_sch              ← PB4
├── sheets/08_usb.kicad_sch
├── sheets/09_connectors.kicad_sch
├── sheets/10_knock_dnp.kicad_sch
├── sheets/11_mcu_h562.kicad_sch          ← desenhada; limpeza
└── sheets/12_can.kicad_sch               ← FDCAN1 + ESD
```

No disco, o root **ainda** aponta a `04_tle8888_hub` e `06_etb` (vazios). Renomear ao
chegar à Fase 3–4 do plano de execução — sem perda de trabalho de copper.

⛔ `hardware/openems_ecu/` (fork mRE) **congelado** — ver
[`../microruseefi_as_base.md`](../microruseefi_as_base.md).

## Processo por módulo

1. Ler (ou reescrever) o `.md` do módulo  
2. Consultar Speeduino/rusEFI + datasheet (§1b em `docs/hw/README.md`)  
3. Confirmar **cada pino MCU** em `pinout_v2.md`  
4. Desenhar **só** esse sheet no KiCad  
5. ERC local (`kicad-cli sch erc`)  
6. Marcar checklist no `.md` e actualizar estado aqui  

## Ordem de execução

1. Limpar sheet 11 (padrão de qualidade)  
2. ~~CKP Hall~~ ✅ doc + sheet (2026-08-08); CMP rascunho a rever  
3. ~~Flex `PB4`~~ ✅ doc + sheet  

4. ~~Refazer `05_analog`~~ ✅ pinout_v2 + netlist 13/13 (2026-08-08)  

5. Reorganizar root + PMIC + `01_power`  
6. MC33810 → L9960T → CJ125 → CAN → USB → conectores → knock  
7. ERC projecto + PDF + BOM  
8. **Fase PCB** (só depois do DoD esquemático)  

## O que NÃO fazer ainda

- Layout / copper / DRC  
- Escolher caixa final  
- Popular knock  
- Inventar símbolos dos 4 CIs sem datasheet  
- Tratar rascunhos `03`/`05`/`07` como “fechados”

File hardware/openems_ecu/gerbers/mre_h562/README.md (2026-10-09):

# Gerbers — microRusEFI copper + STM32H562

**Intent:** production / bring-up board = [rusefi/hw_microRusEfi](https://github.com/rusefi/hw_microRusEfi) layout
with **H562 drop-in** (6 power pads), **not** OpenEMS VGT6 PE* re-route.

| | |
|--|--|
| PCB source | `hardware/openems_ecu/production/openems_mre_h562.kicad_pcb` |
| Base | `hardware/vendor/hw_microRusEfi/micro_rusEFI.kicad_pcb` |
| MCU | **STM32H562VGT6** LQFP100 (same land as F427) |
| TLE / routing | **mRE original** (PD12–15 IGN, PE14–11 INJ, SPI PD5+PB3/4/5, …) |
| Firmware | ~~`BOARD=mre`~~ removed; no current firmware build matches this copper (see `docs/hw/README.md`) |
| Docs | ~~`docs/hw/pinout_mre_bringup.md`~~ (removed) |

## H562 electrical deltas vs F427 on this board

| Pad | F427 | H562 treatment |
|-----|---|---|
| 19 | VDD | **GND** (VSSA) |
| 20 | VSSA | **/ADC/AGND** (VREF-) |
| 48 | PB11 | **VCAP** + C25 2.2µF → GND |
| 49 | VCAP_1 | **GND** (VSS) |
| 73 | VCAP_2 | **/VDD** (VDDUSB) + C26 bulk |
| 98 | PE1 | **VCAP** + C100 2.2µF → GND |

## DRC at export

- Error violations: **649**
- Unconnected items: **2**

Review `drc.json` before ordering. Baseline mRE may already carry residual DRC;
this is **not** the VGT6 experimental bus (that had 500+ target-net shorts).

## Fab package

2-layer. Upload the zip of this folder (or parent `openems_mre_h562_*.zip`).

## Silk branding

- `microRusEFI` / `RUSEFI.COM` → **OpenEMS**
- `STM32F407VG` → **STM32H562VG**
- rusEFI QR logo removed
- Design history credits retained under OpenEMS / H562 header

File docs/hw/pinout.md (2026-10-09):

# OpenEMS — Pinout (RGT6 / VGT6)

**Fonte de verdade do pinout.** Detalhe completo por pino dos dois packages
suportados. O `README.md` mantém apenas o resumo das diferenças e aponta para
aqui. Código de referência: `ecu_sched.cpp` (INJ/IGN BSRR), `hal/out_pins.h`
(mapas + `static_assert` por board), `etb_driver.cpp`, `timer.cpp`
(CKP/CMP/ETB PWM), `adc.cpp`.

O firmware selecciona o package no **build** (não em runtime):

```bash
make firmware BOARD=rgt6   # default — WeAct LQFP64
make firmware BOARD=vgt6   # LQFP100 GPIOE (INJ/IGN/ETB em PE*)
# bins: /tmp/openems-build/bin/openems-rgt6.bin | openems-vgt6.bin
```

## RGT6 vs VGT6 — diferença de pinout

| | **RGT6** (`BOARD=rgt6`, default) | **VGT6** (`BOARD=vgt6`) |
|--|---|---|
| Package | LQFP64 | LQFP100 |
| Portas GPIO | A, B, C | A–E |
| WeAct típica | H562RGT6 | H562VGT6 |
| Flag C | `-DEMS_BOARD_RGT6` | `-DEMS_BOARD_VGT6` |
| Bin | `openems-rgt6.bin` | `openems-vgt6.bin` |

**Porquê divergir:** o RGT6 **não tem port E**. O mapa VGT6 concentrou INJ/IGN/ETB
DIR/PWM em **PE\*** (BSRR único, fiação limpa no LQFP100). No RGT6 esses pinos
**não existem** — INJ/IGN/ETB foram redistribuídos por A/B/C.

### Comparação lado a lado (o que muda)

| Função | **RGT6** (`BOARD=rgt6`) | **VGT6** (`BOARD=vgt6`) | Notas |
|---|---|---|---|
| CKP | **PA0** TIM5_CH1 AF2 | PA0 TIM5_CH1 AF2 | Igual |
| CMP | **PA1** TIM5_CH2 AF2 | PA1 TIM5_CH2 AF2 | Igual |
| UART1 TX/RX | **PA9 / PA10** | PA9 / PA10 | Igual |
| USB DM/DP | **PA11 / PA12** | PA11 / PA12 | Igual |
| CAN | **PB8 / PB9** | PB8 / PB9 | Igual |
| LED | **PB2** | PB2 | Igual |
| **INJ1** | **PA15** | **PE0** | Remap RGT6 |
| **INJ2** | **PB3** | **PE2** | Remap RGT6 |
| **INJ3** | **PC10** | **PE4** | Remap; WeAct: PB10/11 **não** no header |
| **INJ4** | **PC11** | **PE6** | Remap RGT6 |
| **IGN1** | **PC6** | **PE9** | Remap RGT6 |
| **IGN2** | **PC7** | **PE11** | Remap RGT6 |
| **IGN3** | **PC8** | **PE13** | Remap; ⚠️ vs SDMMC PC8 |
| **IGN4** | **PC9** | **PE15** | Remap RGT6 |
| **ETB PWM** | **PA6** TIM3_CH1 AF2 | **PE5** TIM15_CH1 AF4 | Timer e pino diferentes |
| **ETB DIR open** | **PA8** | **PE7** | Remap RGT6 |
| **ETB DIR close** | **PB4** | **PE8** | Remap RGT6 |
| ETB_TPS1 / TPS2 | PA2 / PC5 | PA2 / PC5 | Igual (ADC) |
| EWG PWM | PB10 TIM2_CH3 | PB10 TIM2_CH3 | PB10 livre de INJ no mapa actual (WeAct: pino pode não sair no header) |
| EWG DIR | PA7 (+ PD3 no driver, **sem GPIOD no RGT6**) | PA7 / pino dedicado VGT6 | PD3 inválido no RGT6 |
| Flex / VVT | PB5 / PB6–7 | PB5 / PB6–7 | Igual |
| ADC sensores (MAP…OIL) | ver tabela ADC | mesma atribuição ADC actual | Igual no tree actual |

### Drive eléctrico

| | RGT6 | VGT6 |
|--|---|---|
| INJ/IGN | GPIO **BSRR** multi-porto (A/B/C) | GPIO **BSRR** só **GPIOE** |
| ETB PWM | TIM3 @ PA6 | TIM15 @ PE5 |
| TIM OC (TIM2/TIM8) | **Não usado** | **Não usado** (também BSRR) |

### Conflitos / limitações WeAct RGT6

| Pino | Nota |
|---|---|
| **PB10 / PB11** | No coreboard WeAct **não saem nos headers** — **não usar para INJ** (por isso INJ3/4 = PC10/11) |
| **PC8 / PC9** | IGN3/4; se microSD (SDMMC) activo, colide com D0/D1 |
| **PC10 / PC11** | INJ3/4; colidem com SDMMC D2/D3 se cartão |
| **PD3** | EWG DIR IN2 no driver — **inexistente no RGT6** |

### Fiação ao mudar de placa

- **VGT6 → RGT6:** religar todos os PE\* de INJ/IGN/ETB para a coluna RGT6;
  CKP/CMP/UART/USB/CAN/ADC iguais.
- **RGT6 ↔ VGT6:** gravar o binário correcto (`BOARD=…`). Flash cruzado = pinos
  errados.

## Crank / cam / comms (comum)

| Funcao | Peripheral | Pino |
|---|---|---|
| CKP | TIM5_CH1 AF2 | **PA0** (pull-down) |
| CMP | TIM5_CH2 AF2 | **PA1** (pull-down) |
| UART TX | USART1 AF7 | **PA9** |
| UART RX | USART1 AF7 | **PA10** (pull-up) |
| USB DM/DP | USB AF10 | **PA11 / PA12** |
| CAN RX/TX | FDCAN1 AF9 | **PB8 / PB9** |
| LED heartbeat | GPIO | **PB2** |

## Injecção / ignição — por board

**RGT6** (`BOARD=rgt6`):

| Funcao | Pino | Notas |
|---|---|---|
| INJ1 | **PA15** | header WeAct |
| INJ2 | **PB3** | header WeAct |
| INJ3 | **PC10** | header WeAct (não PB10) |
| INJ4 | **PC11** | header WeAct (não PB11) |
| IGN1 | **PC6** | push-pull |
| IGN2 | **PC7** | |
| IGN3 | **PC8** | ⚠️ vs SDMMC D0 |
| IGN4 | **PC9** | ⚠️ vs SDMMC D1 |

**VGT6** (`BOARD=vgt6`):

| Funcao | Pino | Notas |
|---|---|---|
| INJ1–4 | **PE0 / PE2 / PE4 / PE6** | BSRR GPIOE |
| IGN1–4 | **PE9 / PE11 / PE13 / PE15** | BSRR GPIOE |

Ordem de canais BSRR = `ECU_CH_*`:
`[INJ3, INJ4, INJ1, INJ2, IGN4, IGN3, IGN2, IGN1]`. Actuadores active-high;
safe = LOW. Boot safe: `ecu_sched_outputs_safe_early()` → `out_pins_hw_init()`
(RGT6: PA15 JTDI pull-up; VGT6: PE\* LOW no arranque).

## ETB / EWG / AUX — por board

**RGT6:**

| Funcao | Peripheral | Pino |
|---|---|---|
| ETB PWM | TIM3_CH1 AF2 | **PA6** |
| ETB DIR open (IN1) | GPIO | **PA8** |
| ETB DIR close (IN2) | GPIO | **PB4** |
| ETB_TPS1 / TPS2 | ADC1 | **PA2 / PC5** |
| EWG PWM | TIM2_CH3 | **PB10** (WeAct: pode não sair no header) |
| EWG DIR | GPIO | PA7 / PD3 (PD3 só c/ GPIOD) |
| Flex / VVT | EXTI / TIM4 | **PB5** / **PB6–PB7** |

**VGT6:**

| Funcao | Peripheral | Pino |
|---|---|---|
| ETB PWM | TIM15_CH1 AF4 | **PE5** |
| ETB DIR open / close | GPIO | **PE7 / PE8** |
| ETB_TPS / Flex / VVT / EWG PWM | | iguais à coluna RGT6 (ADC/PB5–7/PB10) |

> Os limites TPS1/TPS2 do ETB são recalibrados a cada power-on por varredura dos
> batentes (`etb_autocal`); a última calibração boa é persistida (EtbCalRecord,
> setor adaptativo) como fallback. Ver README §"ETB".

## Relés — bomba e ventoinha (**difere por package**)

| Funcao | **RGT6** | **VGT6** | Constante |
|---|---|---|---|
| Ventoinha | **PB12** (BSRR GPIOB) | **PE12** (BSRR GPIOE) | `kFanPin` |
| Bomba de combustível | **PB13** (BSRR GPIOB) | **PE10** (BSRR GPIOE) | `kPumpPin` |

Definidos em `src/engine/auxiliaries.cpp` sob `#if EMS_BOARD_IS_VGT6`.
Lógica: `run_pump_control()` faz prime de 2 s no key-on, mantém ligada com
RPM > 0 e **corta 2 s após RPM = 0** (`kPumpOffDelayMs = 2000`); `run_fan_control()`
usa histerese CLT 95 °C liga / 90 °C desliga. Ambos suspensos durante
`output_test_active()`.

**TLE8888:** não é usado nesta ECU (driver removido do firmware). As saídas
INJ/IGN saem direto por GPIO; `PE14` e `PE3` (antigos INJEN/IGNEN) e o SPI2
(`PB12`–`PB15`) ficam livres.

No VGT6 os relés ficam em `GPIOE` (`PE10`/`PE12`). ⚠️ **`PE1` não existe no STM32H562VGTx LQFP100**
(pad 98 = VCAP) — ver `stm32h562_ref.md` §3.1. Restantes PE: INJ PE0/2/4/6,
IGN PE9/11/13/15, ETB PE5/7/8. Partilhar o porto com INJ/IGN é seguro: o
acionamento é por **BSRR**, set/reset atómico por bit, sem read-modify-write.

> ⚠️ **O RGT6 mantém o conflito** — `PB12`/`PB13` continuam a colidir com o SPI2
> lá. O RGT6 não é o alvo da placa de interface; se vier a ser, tem de resolver
> isto (não tem GPIOE). O mesmo SPI2 é candidato a um futuro **TPIC8101** (knock).

## ADC (sensores) — comum nos dois packages (tree actual)

| Funcao | ADC | Pino / INP |
|---|---|---|
| MAP | ADC1 | **PA3** / INP15 |
| TPS | ADC1 | **PA4** / INP18 |
| KNOCK | ADC1 | **PA5** / INP19 |
| ETB_TPS1 | ADC1 | **PA2** / INP14 |
| ETB_TPS2 | ADC1 | **PC5** / INP8 |
| APP1 | ADC1 | **PC0** / INP10 |
| APP2 | ADC1 | **PC2** / INP12 |
| CLT | ADC2 | **PB0** / INP9 |
| IAT | ADC2 | **PB1** / INP5 |
| FUEL_PRESS | ADC2 | **PC4** / INP4 |
| OIL_PRESS | ADC2 | **PC1** / INP11 |
| VBATT | ADC2 | **PC3** / INP13 |

**Nota:** WBO2 lambda exclusivamente via CAN (FDCAN1). Sem ADC O2.

**Nota (VBATT em PC3):** o canal era `EWG_POS`. Com o EWG diferido na placa de
interface v1, `PC3` passou a VBATT com divisor externo 0–18 V → 0–3,3 V. Antes, VBATT
partilhava o pino do `ETB_TPS2` e era **fixada em 12000 mV** com o chicote do ETB
ligado — o que subestimava o dead-time do injetor e encurtava o dwell num cranking
real (a bateria cai a 9–10 V). A realimentação de posição do EWG ficou sem canal:
`ewg_driver_read_position_raw()` devolve 0 até o EWG voltar na v2.

**Histórico de pinout (2026-07):**

- OIL: PC5 → **PC1** (PC5 fica ETB_TPS2).
- Dual-board: `-DEMS_BOARD_RGT6` / `-DEMS_BOARD_VGT6` (`src/hal/board_pinout.h`).
- RGT6 WeAct: INJ3/4 em **PC10/PC11** (PB10/11 não expostos nos headers).
- Boot safe: `ecu_sched_outputs_safe_early()` — PA15 JTDI pull-up e PE\* LOW no arranque.

## Ver também

- **`docs/hw/README.md`** — **ponto de entrada** (autoridade, decisões, em aberto).
- **`docs/hw/interface_board_v1.md`** — *histórico (TLE8888 não é usado)*: plano da placa de interface v1
  (TLE8888-**2QK** como estágio de potência, INJ/IGN por direct drive, alocação de
  pinos, orçamento de erro de timing, sequência de verificação).
- **`docs/wiring_diagram.md`** — ⚠️ **DESACTUALIZADO em vários eixos**: mapa de
  pinos ASCII legado (TIM2/TIM8 OC), e os números do TLE8888 ali ("INJ OC 10 A,
  IGN push-pull 6 A") **estão errados** — o datasheet Rev 1.2 dá injectores
  2,2 A e ignição como driver de gate de 20 mA. Usar apenas como referência de
  topologia eléctrica (terra, conector), e mesmo assim com desconfiança.
- **`docs/hw/vr_input_conditioning.md`** — condicionamento VR. ⚠️ Recomenda o
  MAX9926; no plano v1 o CKP passou a usar a **interface VR integrada do
  TLE8888** (zero-crossing + armamento por pico, clamp e diagnóstico internos).

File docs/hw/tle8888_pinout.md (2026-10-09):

# TLE8888 LQFP-100 — pinout de package (fonte primária)

> ⛔ **Documento histórico.** O TLE8888 não é usado nesta ECU: o driver foi removido do firmware e as saídas INJ/IGN saem direto por GPIO. Mantido só como referência.

> **Fontes:** Infineon TLE8888-1QK Data Sheet **Rev. 1.2** (2017-02-10), §3 Pin Configuration  
> (PDF local de trabalho / download Infineon). Contraprova de nomes: símbolo KiCad  
> `rusefi/hardware/rusefi_lib/tle8888qk.lib` (microRusEFI).  
> Variantes **-1QK / -2QK / QK** partilham o mesmo package e pinout; diferem no watchdog.

**Tier A** para layout KiCad. O que muda por board é só a **fiação MCU ↔ estes pinos**.

---

## SPI single-ended (modo OpenEMS) — strapping obrigatório

Do datasheet (comunicação SPI / single-ended):

| Pino | Símbolo | Ligação SPI |
|---|---|---|
| 3 | **CSN** | ← MCU CS (PB12) |
| 4 | **SDO** | → MCU MISO (PB14) |
| 5 | **SIP** | ← MCU MOSI (PB15) — *data in* |
| 7 | **FCLP** | ← MCU SCK (PB13) — *clock* |
| **6** | **SIN** | → **AGND** (select SPI mode) |
| **8** | **FCLN** | → **VDDIO** (select single-ended) |

⚠️ Sem SIN=AGND e FCLN=VDDIO o CI pode ficar em MSC/LVDS e o SPI “não responde”.  
VDDIO (pino 20) = rail 3,3 V do MCU (mesma lógica dos direct-drive INx).

---

## Mapa OpenEMS v1 (MCU → package)

| Função OpenEMS | MCU | TLE pino | Símbolo DS | Notas |
|---|-----|---|---|---|
| SPI CS | PB12 | **3** | CSN | |
| SPI MISO | PB14 | **4** | SDO | push-pull em SPI |
| SPI MOSI | PB15 | **5** | SIP | |
| SPI SCK | PB13 | **7** | FCLP | |
| SPI mode | — | **6** | SIN | **→ AGND** |
| SPI mode | — | **8** | FCLN | **→ VDDIO** |
| INJEN | PE14 | **24** | INJEN | enable OUT1–4 (⚠️ não PE1: H562VGTx LQFP100 não bonda esse pad) |
| IGNEN | PE3 | **27** | IGNEN | enable IGN1–4 |
| INJ1–4 | PE0/2/4/6 | **28–31** | IN1–IN4 | DD fixo → OUT1–4 |
| IGN1–4 | PE9/11/13/15 | **32–35** | IN5–IN8 | DD fixo → IGN1–4 |
| Bomba | PE10 | **36** | IN9 | → OUT14 (InConfig) |
| Ventoinha | PE12 | **37** | IN10 | → OUT15 |
| VVT esc | PB6 | **38** | IN11 | → OUT5 |
| VVT adm | PB7 | **39** | IN12 | → OUT6 |
| CKP dig | PA0 | **21** | VROUT | push-pull digital |
| CKP+ | conector | **52** | VRIN1 | par diferencial |
| CKP− | conector | **51** | VRIN2 | |
| CAN RX | PB8 | **43** | CANRX | MCU ← CI |
| CAN TX | PB9 | **44** | CANTX | MCU → CI |
| CANH/L | conector | **46/47** | CANH/CANL | |
| +5V sens A/B | sensores | **9/10** | T5V1/T5V2 | trackers |
| Main relay | DNP v1 | **55** | MR | key-on na v1 |
| BAT | rail | **54** | BAT | + BATPA/B 87/90 |
| PGND | estrela | **25,50,75** + tab | PGND | |
| AGND | VSSA | **100** | AGND | |
| VDDIO | +3V3 | **20** | VDDIO | lógica I/O |

---

## Tabela completa LQFP-100 (datasheet §3.2)

| Pin | Símbolo | Dir | Função (resumo DS) |
|-----|---|-----|---|
| 1 | RST | I/O | Reset bidirecional |
| 2 | MON | I/O | Monitor bidirecional |
| 3 | CSN | IN | SPI/MSC chip select |
| 4 | SDO | OUT | SPI/MSC data out |
| 5 | SIP | IN | SPI data in (single-ended) / LVDS+ data |
| 6 | SIN | IN | SPI select (**AGND** em SPI) / LVDS− data |
| 7 | FCLP | IN | SPI clock / LVDS+ clock |
| 8 | FCLN | IN | SPI select (**VDDIO** em SPI) / LVDS− clock |
| 9 | T5V1 | OUT | Tracker 5 V sensores A |
| 10 | T5V2 | OUT | Tracker 5 V sensores B |
| 11 | V5V | OUT | 5 V main ECU |
| 12 | V6V | IN | Source pré-regulador externo |
| 13 | VG | OUT | Gate pré-regulador externo |
| 14–16 | OUT7A/B/C | OUT | LS 4,5 A — **ligar A+B+C juntos** |
| 17 | OUT20 | OUT | LS pequeno |
| 18 | OUT19 | OUT | LS pequeno |
| 19 | n.c. | — | aberto ou GND |
| 20 | VDDIO | SUP | Supply lógica I/O (3,3 V) |
| 21 | VROUT | OUT | Saída digital VR |
| 22 | LINTX | IN | LIN TX |
| 23 | LINRX | OUT | LIN RX |
| 24 | **INJEN** | IN | Enable injectores OUT1–4 |
| 25 | PGND | GND | Power ground |
| 26 | KOFFDO | OUT | Key-off delay |
| 27 | **IGNEN** | IN | Enable ignição IGN1–4 |
| 28–31 | IN1–IN4 | IN | DD injectores |
| 32–35 | IN5–IN8 | IN | DD ignição |
| 36–39 | IN9–IN12 | IN | DD mapeáveis (InConfig) |
| 40 | EOTEN | IN | Engine-off timer enable |
| 41 | V5VSTBY | OUT | 5 V standby |
| 42 | CANWKEN | IN | CAN wake enable |
| 43 | CANRX | OUT | CAN RX → MCU |
| 44 | CANTX | IN | CAN TX ← MCU |
| 45 | V5VCAN | SUP | 5 V CAN |
| 46 | CANH | I/O | Bus |
| 47 | CANL | I/O | Bus |
| 48 | WK | IN | Wake |
| 49 | KEY | IN | Key (+ supply path MR) |
| 50 | PGND | GND | |
| 51 | VRIN2 | IN | VR diferencial − |
| 52 | VRIN1 | IN | VR diferencial + |
| 53 | BATSTBY | SUP | Battery standby |
| 54 | BAT | SUP | Battery main |
| 55 | MR | OUT | Main relay low-side |
| 56–58 | OUT18–16 | OUT | LS relé |
| 59–60 | OUT1A/B | OUT | Injector 1 — **A+B juntos** |
| 61–62 | OUT2A/B | OUT | Injector 2 |
| 63–64 | OUT3A/B | OUT | Injector 3 |
| 65–66 | OUT4A/B | OUT | Injector 4 |
| 67 | OUT15 | OUT | LS (fan OpenEMS) |
| 68 | OUT14 | OUT | LS (pump OpenEMS) |
| 69–74 | DFB8–10 / OUT8–10 | | MOSFET on-board drivers |
| 75 | PGND | GND | |
| 76–81 | DFB11–13 / OUT11–13 | | MOSFET drivers |
| 82 | LINIO | I/O | LIN bus |
| 83–85 | OUT5A/B/C | OUT | LS 4,5 A VVT — **A+B+C juntos** |
| 86 | OUT24 | OUT | Half-bridge |
| 87 | BATPA | SUP | Bat half-bridges/CP — **ligar a BATPB** |
| 88–89 | OUT23–22 | OUT | Half-bridge |
| 90 | BATPB | SUP | com BATPA |
| 91 | OUT21 | OUT | Half-bridge |
| 92–94 | OUT6A/B/C | OUT | LS 4,5 A VVT 2 — **A+B+C juntos** |
| 95 | CP | OUT | Charge pump (cap externa) |
| 96–99 | IGN1–4 | OUT | Push-pull **gate IGBT** (20 mA) |
| 100 | AGND | GND | Signal ground |
| tab | PGND | GND | Exposed pad |

---

## Regras de layout (datasheet)

1. **OUT1A+OUT1B** (e 2/3/4) no mesmo nó, sem parasitagem entre A e B.  
2. **OUT5A+B+C**, **OUT6A+B+C**, **OUT7A+B+C** idem.  
3. **BATPA ↔ BATPB** sem parasitagem.  
4. **PGND pins + cooling tab** num pour de potência.  
5. **IGN1–4**: DS diz *“on- or off-board IGBT”* — **não** assume smart coil 5 V lógica sem medir V_OH / V_IH da bobina.

---

## Correção ao texto stale

Afirmações antigas “pino 24/27 não verificados” estão **obsoletas**: o datasheet e o símbolo rusEFI concordam.  
O que era inventado era o **mapa de registadores SPI**, não estes pinos de package.

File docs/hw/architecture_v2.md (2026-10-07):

# Arquitectura v2 — CIs dedicados no lugar do hub TLE8888

> **Decisão (2026-08-07).** A ECU passa de um hub único (TLE8888-2QK) para CIs dedicados
> por função. Origem: especificação externa, verificada bloco a bloco antes de adoptada.

## Os CIs

| Função | v2 | Substitui |
|---|---|---|
| PMIC / SBC | **TI TPS65381A-Q1** — pre-buck 6 V, LDO 3,3 V, LDO 5 V VTRACK ratiométrico, window watchdog | reguladores do TLE8888 |
| INJ / IGN | **NXP MC33810** — 4× low-side 4,5 A + 4× gate driver de bobina smart | direct drive do TLE8888 |
| ETB + EWG | **ST L9960T** — ponte dupla, PWM+DIR + SPI | BTS7960 (ETB) e EWG diferido |
| Wideband O2 | **Bosch CJ125** + LSU 4.9, aquecedor por HITFET BTS3134D | — (era WBO2 externo por CAN) |
| CAN | **FDCAN1 único** + expansor de I/O por SPI | transceiver do TLE8888 |

## ⚠️ O que esta decisão ANULA

Estas estavam fechadas e deixam de valer. Registado aqui para não voltarem por inércia:

| Decisão anulada | Era |
|---|---|
| TLE8888-2QK como hub | `a5f95fb` |
| INJ/IGN por direct drive do TLE | `a5f95fb` |
| CKP pela interface VR do TLE8888 | — |
| CAN pelo transceiver do TLE8888 | `netlist_v1.md` Bloco 9 |
| EWG diferido para a v2 | `34b40e3` — **agora é populado** |
| `-2QK` escolhida por trazer o watchdog desactivado | o TPS65381A tem window watchdog **obrigatório** |
| ~~Rejeição do DRV8701 por ser de 2 pinos~~ | o L9960T é igualmente 2 pinos e **foi aceite** |

## O que SOBREVIVE intacto

VGT6 / LQFP100 · H562 soldado · AMPSEAL 35+23 · montagem na cabine · USB isolado ·
4 camadas · VREF+ = VDDA filtrado · WeAct só bancada · knock diferido ·
**VBATT em `PC3`/INP13** · **scheduler congelado**.

## Porque o scheduler NÃO sai do congelamento

O MC33810 tem entradas paralelas directas para o caminho crítico — a mesma forma que
justificou o direct drive do TLE8888. Como o GPIOE tem 15 pinos bondados, os 8 inputs
ficam **nos mesmos pinos de hoje** (`PE0/2/4/6` + `PE9/11/13/15`).

`kOutBsrrPin[] = {4,6,0,2, 15,13,11,9}` **não muda**. `out_pin_write` mantém a escrita
BSRR única e atómica. O jitter de ~0,4 µs validado em hardware mantém-se.

## Três problemas que a spec original tinha e foram corrigidos

1. **`FDCAN2` não existe** no H562VGTx LQFP100 — derrubava o pilar da "rede auxiliar".
   Resolvido com barramento único + expansor por SPI.
2. **Matriz de pinos com 25 de 45 números errados**, incluindo `VBAT_SENSE` no `VDDA`.
   Descartada e refeita em [`pinout_v2.md`](pinout_v2.md), validada contra o symbol.
3. **CKP/CMP em `PE9`/`PE10`** — sem TIM2/TIM3 nesses pinos, e colidia com IGN1.
   Voltaram a `PA0`/`PA1`, onde o TIM5 os põe no timebase do scheduler.

## Dívida de firmware (enumerada, NÃO implementada)

Nada disto foi escrito. É um projecto próprio, a dimensionar deliberadamente.

| Item | Estado |
|---|---|
| `src/hal/tle8888.cpp` + `tle8888_regs.h` | **reformam-se** — ~20 KB de driver, reescrito contra o DS Rev 1.2 há dias |
| Driver TPS65381A-Q1 | novo — **e o window watchdog tem de ser servido**, ao contrário da `-2QK` |
| Driver MC33810 | novo — SPI de configuração; o caminho de timing continua a ser GPIO directo |
| Driver L9960T | novo |
| Driver CJ125 | novo — e `sensors.h` volta a ter caminho analógico de lambda (`o2_mv` tinha sido removido de propósito) |
| `etb_driver.cpp` | **reescrita** de 3 pinos (PWM+IN1+IN2) para 2 (PWM+DIR) + SPI |
| `ewg_driver.cpp` | tirar a guarda `EMS_EWG_POPULATED 0`, PID com realimentação real em `PA7` |
| `adc.h` | remapear canais; entram `LAMBDA_UA`/`UR`, `APP1`/`APP2`, `EWG_POS` |
| Expansor de I/O por SPI | novo, sem part number ainda |

## ✅ CKP decidido: Hall, igual ao CMP (2026-08-07)

Com o TLE8888 fora não há interface VR integrada — **CKP passa a Hall**, mesmo
condicionamento do CMP (divisor 10k/3,3k + RC + clamp dual BAT54BRW, da spec §7).
**Isto muda o sensor exigido ao motor**: uma roda dentada lida por VR deixa de servir:
precisa de sensor Hall (ou VR + condicionador externo fora da placa, não avaliado).

### ✅ Mecanismo de polaridade FECHADO (2026-08-07) — só falta o RISING/FALLING

Explorado e rejeitado: captura das **duas arestas** (`CCxP+CCxNP`, "modo Both" do rusEFI)
como forma de evitar ter de escolher. Três razões, por ordem de peso:

1. **O STM32 não diz qual aresta disparou** a captura nesse modo. As únicas formas de
   inferir — ler o GPIO logo a seguir, ou alternar um flag por software — já falham por
   razões que o nosso próprio `ckp_tim5_ch1_isr()` documenta (leitura de GPIO pós-captura
   é o anti-padrão que o filtro por período mínimo foi escrito para evitar) ou porque o
   filtro anti-glitch descarta pulsos de propósito, dessincronizando qualquer flag.
2. **O próprio rusEFI usa `SyncEdge::RiseOnly`** para todo decoder de roda dentada
   uniforme — incluindo o `TT_TOOTHED_WHEEL_60_2`, a mesma roda que a nossa
   (`trigger_structure.cpp:665-666`). `Both` só aparece em decoders de came com
   larguras de dente deliberadamente desiguais (Mazda/Mitsubishi/Nissan) — um problema
   de codificar posição, não de contar dentes uniformes. Um autor do próprio projecto
   documentou uma tentativa falhada de usar `Both` num caso **mais simples** que o nosso
   (roda de um dente): *"the Trigger can't become synchronized by 'last' and followed
   'first' events only... For now, ::Rise work well"* (`trigger_misc.cpp:127-141`).
3. Mesmo que a identificação de aresta fosse resolvida, só dá espaçamento angular
   uniforme com duty cycle **exactamente 50%** — propriedade do sensor Hall que ainda
   não tem part number. Fora disso, introduz um segundo padrão de outlier por cima do
   gap real, que o `TOOTH_GRD` (`src/drv/ckp.cpp`) não foi desenhado para separar.

**O mecanismo em si já está implementado** (commit `4368e15`): `page0[258]` bits 0/1 +
`tim5_ic_set_capture_polarity()` — RISING **ou** FALLING, um só, calibrável, o mesmo
modelo do `TrigEdge` do Speeduino e do `RiseOnly` que o rusEFI usa para 60-2.

## O que ficou por decidir

- **Só a escolha RISING vs FALLING** para CKP e CMP — pendente do datasheet do Hall
  escolhido (idle HIGH + pulso LOW → descida é o início físico do dente; recomendação
  registada é descida, ver memória `cmp-ckp-capture-edge-polarity`). Não é decisão de
  esquemático nem exige reabrir o firmware — é escrever dois bits de calibração.
- Part number do expansor de I/O.
- Se `VVT`/`PUMP`/`FAN` precisam de PWM real — o GPIOE não tem timer utilizável.

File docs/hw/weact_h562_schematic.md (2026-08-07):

# WeAct STM32H5xx VxTx CoreBoard V1.0 — esquemático (resumo OpenEMS)

> **Fonte:** `WeAct-STM32H5xxVxTxCoreBoard_V10 SchDoc.pdf` (Altium, 1 página).  
> Arquivo: `docs/hw/weact_h562_v10_schdoc.pdf`.  
> Forma mecânica: `weact_h562_coreboard.md`.

Não substitui o PDF. Extrai o que a **placa de interface** precisa: rails, headers dual-row
**P1 / P2**, USB, SWD, e presença de **GPIOE** (VGT6).

---

## Rails e alimentação (coreboard)

| Net no sch | Uso |
|---|-----|
| **VDD33** | 3,3 V LDO onboard → VDD MCU |
| **VCC / 5V** | 5 V (USB / header) |
| **VB** | Vin wide (header P2 pin 1) — entrada do regulador da board |
| **GND** | comum |
| **VREF+** | pino MCU VREF+ exposto no header P1 |

A carrier OpenEMS **não deve alimentar sensores ratiométricos pelo 5 V ruidoso do USB**;
usa trackers T5V1/T5V2 do TLE8888. O coreboard pode ser alimentado por **+3V3** da carrier
ou por VB/5V conforme escolha de montagem — documentar no esquemático da interface.

---

## Conectores laterais dual-row (P1 / P2)

Passo **2,54 mm**, ~**40 vias por lado** (2×20). Numeração do sch: pin ímpar/par por fila
(`PIP10x` = P1, `PIP20x` = P2).

### P1 (COP1) — sinais relevantes OpenEMS

| Pins P1 | Sinal | OpenEMS |
|---:|---|---|
| 1–2 | PC0 / PC1 | APP1 / OIL (ADC) |
| 3–4 | PC2 / PC3 | APP2 / VBATT ADC |
| 5–6 | GND / **VREF+** | AGND / VREF (opção (a) liga a VDDA) |
| 7–8 | **PA0 / PA1** | **CKP / CMP** |
| 9–10 | PA2 / PA3 | ETB_TPS1 / MAP |
| 11–12 | PA4 / PA5 | TPS / KNOCK |
| 13–14 | PA6 / PA7 | (RGT6 ETB PWM etc.; VGT6 ETB em PE) |
| 15–16 | PC4 / PC5 | FUEL_PRESS / ETB_TPS2 |
| 17–18 | PB0 / PB1 | CLT / IAT |
| 19–20 | PB2 / PE7 | LED / **ETB DIR open** |
| 21–22 | **PE8 / PE9** | **ETB DIR close / IGN1** |
| 23–24 | **PE10 / PE11** | **bomba / IGN2** |
| 25–26 | **PE12 / PE13** | **ventoinha / IGN3** |
| 29–30 | **PB12 / PB13** | **SPI2 CS / SCK → TLE** |
| 31–32 | **PB14 / PB15** | **SPI2 MISO / MOSI** |
| 33–38 | PD8–PD13 | livres / SDMMC potencial |
| … | PD… | ver PDF |

### P2 (COP2) — sinais relevantes OpenEMS

| Pins P2 | Sinal | OpenEMS |
|---:|---|---|
| 1–2 | **VB** / PE6 | Vin board / **INJ4** |
| 3–4 | **PE4 / PE5** | **INJ3 / ETB PWM** |
| 5–6 | **PE2 / PE3** | **INJ2 / IGNEN** |
| 7–8 | **PE0** / … | **INJ1** / … |
| 9–10 | **PB8 / PB9** | **CAN RX / TX** |
| 11–12 | **PB6 / PB7** | **VVT TIM4** |
| 13–14 | PB4 / … | |
| 15–16 | PD7 / PB3 | |
| 27–28 | **PA10 / PA11** | UART RX / **USB DM** |
| 29–30 | **PA8 / PA9** | / **USB? / UART TX** — ver PDF (USB em PA11/12) |
| 31–36 | PC8–PC9, PC6–PC7, PD14–15 | SDMMC / livres |

⚠️ A tabela acima foi **derivada do SchDoc export** (nomes PIP + nets); cruzar **pin 1**
com silkscreen da peça física antes de mandar fabricar a carrier. O PDF Board Shape +
SchDoc juntos fecham forma e netlist de headers.

---

## USB / SWD / botões

- **USB-C** na base: DP/DM → PA12/PA11 (via ESD típico no sch).  
- **SWD** header 6 vias: 3V3, SWDIO (PA13), SWCLK (PA14), GND, NRST, …  
- **NRST**, **BOOT0** botões; LED **PC13** / PWR.

Isolador USB da interface: cortar o laço **no cabo** ou no conector da carrier, não
assumir que o USB-C do WeAct fica acessível com a board encaixada na caixa.

---

## Checklist carrier ↔ WeAct

- [ ] Footprint dual-row 2,54 mm P1/P2 com pin 1 no canto correcto  
- [ ] Furos M3 Φ3,2 @ grelha `weact_h562_coreboard.md`  
- [ ] Todos os PE* de INJ/IGN/ETB/enables passam por header  
- [ ] PB12–15 só TLE SPI (sem bomba/fan)  
- [ ] PA0/PA1 CKP/CMP; PB8/9 CAN  
- [ ] VREF+ / VDDA conforme opção (a)

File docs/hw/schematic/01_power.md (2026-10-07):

# Sheet 01 — Alimentação (entrada / protecção)

## Função
Entrada de bateria no AMPSEAL J2 → **protecção de polaridade + fusível + TVS + bulk**
→ rail `VBAT` limpo para o resto da placa.

Na arquitectura **v2**, buck / LDO / trackers 5 V de sensor vivem no **TPS65381A-Q1**
(sheet `04_pmic_tps65381`, ainda por desenhar). Este sheet **não** regula 3,3 V nem 5 V.

## Referência (Speeduino / rusEFI)
- rusEFI / microRusEFI: TVS no 12 V, bulk, main-relay / key-on.
- Speeduino: fusível + diodo ou P-FET reverse.

**Adoptamos:** P-FET reverse + fusível + SMBJ24CA + bulk 100 µF + 100 nF.  
**Adaptamos:** sem buck/LDO aqui (vão para o PMIC); key-on directo (sem power-latch MCU).  
**Rejeitamos:** AMS1117 / LM2596; alimentar sensores por USB; TLE8888 BAT/trackers.

## Topologia

```
J2.VBAT+ ── F1 30A ── VBAT_RAW ──┬── Q1 P-MOS source
                                 │         │
                                 │        gate ── R_g 100k ── PGND
                                 │         │
                                 │        (R_gs 1M opcional source–gate)
                                 │         │
                                 └──────── drain ── VBAT ──┬── C_bulk 100µF ── PGND
                                                           ├── C 100nF ── PGND
                                                           └── D_tvs SMBJ24CA ── PGND
                                                                    (cátodo a VBAT)

J2.VBAT- / chassis ── PGND

Star (layout): PGND · SGND · AGND unem-se num ponto perto desta entrada
(net-tie no layout; no esquemático partilham labels + PWR_FLAG).
```

Key-on: **VBAT directo** (sem main-relay na path de alimentação da ECU).  
Main-relay de actuadores: GPIO `MAIN_RELAY` / `PE14` (sheet de drive / conectores).

## Componentes

| Ref | Valor / PN | Notas |
|-----|---|---|
| F1 | 30 A blade / poly | acessível; `Device:Fuse` |
| Q1 | P-MOSFET automotive logic-level | `Device:Q_PMOS_GSD` — PN BOM (ex. IRF7416 class / 40 V+) |
| R1 | 100 k | gate → PGND (liga o FET com polaridade correcta) |
| R2 | 1 M (opc.) | gate–source, anti-flutuação |
| D1 | **SMBJ24CA** | cátodo a `VBAT`, ânodo `PGND` |
| C1 | 100 µF low-ESR ≥35 V | bulk |
| C2 | 100 nF 50 V | HF |

## Nets exportadas
`VBAT`, `VBAT_RAW`, `PGND`, `SGND`, `AGND`  
(`+3V3`, `VDDA`, `+5V_SENS_*` → sheet PMIC)

## Checklist
- [x] Doc v2 sem buck/TLE (2026-08-08)
- [x] Sheet desenhada + ERC
- [ ] PN exacto do P-FET e do fusível no BOM
- [ ] Star GND no layout (net-tie)
- [ ] PMIC sheet produz `+3V3` / trackers

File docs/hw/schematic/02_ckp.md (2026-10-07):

# Sheet 02 — CKP (Hall)

## Função
Sensor Hall de roda dentada (60-2) → pull-up 5 V → divisor 3,3 V → **`PA0`**
(`TIM5_CH1`). Mesmo timebase do scheduler que o CMP (`PA1`/`TIM5_CH2`).

Autoridade de pino: [`../pinout_v2.md`](../pinout_v2.md) (`CKP_IN`).  
Decisão Hall (não VR): [`../architecture_v2.md`](../architecture_v2.md).

⚠️ **Isto muda o sensor exigido ao motor:** roda lida por VR deixa de servir na placa
— precisa de Hall (ou VR + condicionador **externo**, fora do âmbito desta sheet).

## Referência
- **CMP deste projecto** (`03_cmp.md`) — topologia irmã; mesmos valores.
- rusEFI / Speeduino hall notes: open-collector → pull-up ~1 k–10 k a 5 V.
- ~~Interface VR do TLE8888~~ — **rejeitada** com a v2 (TLE saiu).

**Adoptamos:** pull-up a **+5V_SENS_A** + divisor 10k/15k + Rfilt + C + TVS 3,3 V
(igual ao CMP).  
**Adaptamos:** pino `PA0` (TIM5_CH1); polaridade em firmware `page0[258]` bit0 + PUPDR.  
**Rejeitamos:** interface VR discreta na placa; partilhar condicionamento com o CMP
num único canal; filtro RC agressivo (atrasa o dente e o gap 60-2).

## Topologia

```
+5V_SENS_A ── Rpu 10k ──┬── J1.CKP_SIG (N_CKP_RAW)
                        │
                        ├── Rdiv1 10k ──┬── N_CKP_DIV ── Rfilt 330 ──┬── MCU.PA0
                        │               │                              │
                        │            Rdiv2 15k                      C 330pF
                        │               │                              │
                        │             SGND                          AGND
                        │
                     TVS 3.3V ── AGND

J1.CKP_5V  ← +5V_SENS_A   (alimentação do sensor no conector)
J1.CKP_GND ← SGND
```

Valores (iguais ao CMP, 2026-08-07 no rascunho `03_cmp`):

| Função | Valor | Nota |
|---|---|---|
| Rpu | 10 k | ~0,5 mA se OC a GND; subir corrente (1–4k7) se o Hall o pedir |
| Divisor | 10 k / 15 k 1% | 0–5 V → 0–3 V (margem ao 3,3 V ADC/GPIO) |
| Rfilt | 330 Ω | com 330 pF → τ ≈ 100 ns — leve, não come dentes |
| C | 330 pF C0G | no lado 3,3 V |
| TVS | 3,3 V unidirectional | no nó 3,3 V (após divisor), não no raw 5 V |

**Firmware:** polaridade RISING/FALLING ainda **pendente** do datasheet do Hall
(mecanismo de calibração já existe — `page0[258]` bit0). Default actual do firmware
é subida; confirmar antes do motor real.

## Componentes (sheet)

| Ref | Valor | Footprint |
|-----|---|---|
| R10 | 10 k (Rpu) | R_0603 |
| R11 | 10 k (div hi) | R_0603 |
| R12 | 15 k (div lo) | R_0603 |
| R13 | 330 (Rfilt) | R_0603 |
| D2 | TVS 3V3 uni | SOD-323 / SMB class — PN BOM depois |
| C2 | 330 pF C0G | C_0603 |

Refs `R10–R13` / `D2` / `C2` para não colidir com o rascunho `03_cmp` (`R1–R4`/`D1`/`C1`).

## Nets
`N_CKP_RAW`, `N_CKP_DIV`, `MCU.PA0`, `J1.CKP_SIG`, `+5V_SENS_A`, `SGND`, `AGND`

## Checklist
- [x] Doc reescrito como Hall (não VR/TLE) — 2026-08-08
- [x] Pino = `PA0` / TIM5_CH1 (`pinout_v2`)
- [x] Topologia = espelho de `03_cmp` (mesmos valores R/C/TVS)
- [ ] Pull-up a 5 V sensores, não a 3,3 V MCU
- [ ] TVS no nó 3,3 V (pós-divisor)
- [ ] Part number Hall CKP → fechar bit polaridade RISING/FALLING
- [x] Sheet `02_ckp.kicad_sch` desenhada (2026-08-08) — clone de `03_cmp` com nets
      `J1.CKP_SIG` / `MCU.PA0` / `N_CKP_DIV`, refs R10–R13/D2/C2; ERC sheet **0 erros**
- [ ] Title block formal (hoje: texto de título no canvas)
- [x] Global `MCU.PA0` na sheet 11 — netlist projecto: U1/23 + R13 + C2 (2026-08-08)

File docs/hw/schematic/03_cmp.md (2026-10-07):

# Sheet 03 — CMP (Hall)

## Função
Sensor Hall open-collector de came → pull-up 5 V → divisor 3,3 V → **`PA1`**
(`TIM5_CH2`). Irmão do CKP (`02_ckp.md` → `PA0`/`TIM5_CH1`); mesmo timebase TIM5.

Autoridade: [`../pinout_v2.md`](../pinout_v2.md) (`CMP_IN`).

## Referência
- rusEFI VR_Board / hall notes: OC sink → pull-up ~1 k–10 k, ~5 mA.
- Speeduino: `TrigEdge` / cam edge configurável; pull-up common.
- **CKP v2** (`02_ckp.md`) — mesma topologia e valores.

**Adoptamos:** pull-up a **+5V_SENS_A** + divisor 10k/15k + Rfilt 330 + C 330pF + TVS 3,3 V.  
**Adaptamos:** polaridade em firmware `page0[258]` bit1 + PUPDR (pull-up se falling).  
**Rejeitamos:** partilhar canal VR (TLE saiu); RC agressivo (CMP só resolve fase, mas
não deve atrasar dezenas de µs).

## Topologia

```
+5V_SENS_A ── Rpu 10k ──┬── J1.CMP_SIG (N_CMP_RAW)
                        │
                        ├── R1 10k ──┬── N_CMP_DIV ── Rfilt 330 ──┬── MCU.PA1
                        │            │                              │
                        │         R2 15k                         C 330pF
                        │            │                              │
                        │          SGND                          AGND
                        │
                     TVS 3.3V ── AGND

J1.CMP_5V ← +5V_SENS_A
J1.CMP_GND ← SGND
```

Valores alinhados com `02_ckp` (2026-08-08): divisor 10k/15k → 0–5 V mapeia 0–3 V;
Rfilt 330 + 330 pF C0G (τ ~100 ns).

**Firmware:** se Hall idle HIGH / pulso LOW → page0[258] bit1=1 (falling) + pull-up
interno. RISING/FALLING final pendente do PN do Hall.

## Componentes (sheet actual)

| Ref | Valor | Footprint |
|-----|---|---|
| R1 | 10 k (Rpu) | R_0603 |
| R2 | 10 k (div hi) | R_0603 |
| R3 | 15 k (div lo) | R_0603 |
| R4 | 330 (Rfilt) | R_0603 |
| D1 | TVS 3V3 uni | — PN BOM depois |
| C1 | 330 pF C0G | C_0603 |

## Nets
`N_CMP_DIV`, `MCU.PA1`, `J1.CMP_SIG`, `+5V_SENS_A`, `SGND`, `AGND`

## Checklist
- [x] Topologia Hall (não VR)
- [x] Pino = `PA1` / TIM5_CH2
- [x] Valores = espelho do CKP (10k/15k, 330, 330pF, TVS 3V3)
- [x] Sheet rascunho existe (`03_cmp.kicad_sch`) + título no canvas
- [ ] ERC / polish profissional (title block formal)
- [x] Global `MCU.PA1` na sheet 11 — netlist projecto: U1/24 + R4 + C1 (2026-08-08)
- [ ] Part number Hall CMP → bit polaridade

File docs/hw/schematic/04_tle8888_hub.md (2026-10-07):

# Sheet 04 — Hub TLE8888-2QK — ⛔ ANULADO, o hub único deixou de existir

> ⛔ **Anulado (2026-08-07).** A arquitectura v2 tirou o TLE8888 por completo — ver
> [`../architecture_v2.md`](../architecture_v2.md). Não há mais **um** CI de potência: as
> funções abaixo espalham-se por quatro peças novas, cada uma com o seu próprio SPI CS
> (`docs/hw/pinout_v2.md`):
>
> | Função deste sheet | CI v2 | Doc de bloco |
> |---|---|---|
> | Injectores + ignição (gate) | **MC33810** | ⚠️ não escrito |
> | VVT, relés (drive discreto) | continuam GPIO simples, sem CI dedicado | — |
> | CAN | **FDCAN1 nativo do MCU** + expansor de I/O SPI | ⚠️ não escrito |
> | Watchdog/reguladores (a razão de ser da `-2QK`) | **TPS65381A-Q1** | ⚠️ não escrito |
>
> A entrada VR de CKP nunca dependeu deste sheet no papel — vivia no sheet 02 — mas o
> `VROUT` físico vinha do TLE. Está morta na mesma (CKP é Hall na v2).
>
> **Nenhum destes docs de bloco existe ainda.** Este ficheiro fica como registo do que o
> hub fazia, para quem for desenhar os blocos novos não perder nenhuma função pelo caminho.
> Não desenhar esta sheet — não redesenhar `sheets/04_tle8888_hub` sem primeiro decidir a
> nova divisão de sheets (provavelmente 4, não 1).

## Função (stale — hub TLE8888, ver banner acima)
Único CI de potência/comunicação: injectores, ignição (gate), VVT, relés, CAN, VR (sheet 02),
trackers 5 V, SPI config. Variante **-2QK** (WD off).

## Referência
- rusEFI `tle8888.cpp` + `hardware/rusefi_lib/tle8888qk.lib` + microRusEFI.  
- Crosscheck: `../tle8888_crosscheck.md`, pinout: `../tle8888_pinout.md`.  
**Adoptamos:** direct drive IN1–8, InConfig IN9–12, SPI single-ended strap, CAN integrado.  
**Adaptamos:** pinos MCU PE*/PB* OpenEMS; bomba/fan OUT14/15; VVT OUT5/6.  
**Rejeitamos:** FETs discretos INJ; TJA1051; MAX9924; WD service na v1.

## Sub-blocos no mesmo sheet (ou hierarquia interna)

### 4a — Power IC
- BAT p54 + BATPA/B 87/90 + bulk  
- PGND 25/50/75 + exposed pad → `PGND`  
- VDDIO p20 ← `+3V3`  
- T5V1 p9 → `+5V_SENS_A` (100 nF local)  
- T5V2 p10 → `+5V_SENS_B`  
- V5V p11 / V5VSTBY p41: bulk se usados; senão DNP  
- CP p95: cap charge-pump por DS  
- MR p55: footprint → J2.MAIN_RLY **DNP v1**

### 4b — SPI (single-ended) 🚨

```
MCU.PB12 ── CSN   p3
MCU.PB13 ── FCLP  p7   (SCK)
MCU.PB14 ── SDO   p4   (MISO)
MCU.PB15 ── SIP   p5   (MOSI)
AGND     ── SIN   p6   ★ strap SPI
+3V3     ── FCLN  p8   ★ strap single-ended
+3V3     ── VDDIO p20
```

Series 22–33 Ω opcional em SCK/MOSI se EMI; CS limpo.

### 4c — Direct drive INJ / IGN

| MCU | TLE in | TLE out | Conector |
|-----|---|---|---|
| PE0 | IN1 p28 | OUT1A+B p59+60 | J2.INJ1 |
| PE2 | IN2 p29 | OUT2A+B | J2.INJ2 |
| PE4 | IN3 p30 | OUT3A+B | J2.INJ3 |
| PE6 | IN4 p31 | OUT4A+B | J2.INJ4 |
| PE14 | INJEN p24 | — | — (⚠️ não PE1: LQFP100 não bonda esse pad) |
| PE9 | IN5 p32 | IGN1 p96 | J2.IGN1 |
| PE11 | IN6 p33 | IGN2 p97 | J2.IGN2 |
| PE13 | IN7 p34 | IGN3 p98 | J2.IGN3 |
| PE15 | IN8 p35 | IGN4 p99 | J2.IGN4 |
| PE3 | IGNEN p27 | — | — |

OUT1A deve soldar-se a OUT1B na mesma net (sem indutância entre A/B). Idem 2–4.  
**+12 V injectores/bobinas no chicote**, não na placa.  
IGN: saída gate IGBT — series R gate se IGBT externo; se smart coil, validar níveis.

### 4d — Relés e VVT

| MCU | IN | OUT | Uso |
|-----|----|-----|-----|
| PE10 | IN9 p36 | OUT14 p68 | bomba |
| PE12 | IN10 p37 | OUT15 p67 | ventoinha |
| PB6 | IN11 p38 | OUT5A+B+C p83–85 | VVT esc |
| PB7 | IN12 p39 | OUT6A+B+C p92–94 | VVT adm |

### 4e — CAN

```
MCU.PB9 ── CANTX p44
MCU.PB8 ── CANRX p43
CANH p46 ── J1.CANH ── 120Ω jumper ── J1.CANL ── CANL p47
V5VCAN p45 ← +5V (V5V do TLE ou rail limpo — ver DS correntes)
```

### 4f — VR
Ver sheet 02 (só pinos no hub).

## Checklist
- [ ] SPI straps SIN/FCLN  
- [ ] OUT1–4 A+B shorted on copper  
- [ ] OUT5/6 A+B+C shorted  
- [ ] BATPA–BATPB shorted  
- [ ] INJEN/IGNEN default LOW no MCU  
- [ ] Sem +12 V coil/inj no conector de potência da ECU

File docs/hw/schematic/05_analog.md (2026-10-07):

# Sheet 05 — Condicionamento ADC

## Função
Sensores ratiométricos, NTC e VBATT → ADC1 do H562. **Mapa de pinos só de
`pinout_v2.md`** (não da tabela pré-v2).

## Referência
- Speeduino / rusEFI: divisor + RC + clamp; ADC a **3,3 V** → divisor 10k/15k
  (0–5 V → 0–3 V).
- APP1/APP2 em rails 5 V **diferentes** (plausibilidade de rail).
- LAMBDA_UA/UR vêm do **CJ125** (sheet 04d); aqui só RC leve + TVS no lado MCU.

**Adoptamos:** TVS 3,3 V por canal no nó ADC; pull-up NTC 2,49 k a `+5V_SENS_A`;
VBATT divisor 47k/10k (0–18 V → ~0–3,1 V).  
**Adaptamos:** canais v2 (`LAMBDA_*`, `EWG_POS`); dual tracker A/B (não TLE).  
**Rejeitamos:** knock activo (sheet 10 DNP); mapa pré-v2 (MAP em PA3, etc.).

## Rede padrão ratiométrica (0,5–4,5 V → ~0,3–2,7 V)

```
J1.SIG ── Rdiv 10k ──┬── Rf 1k ──┬── MCU.Pxx
                     │           │
                  Rlo 15k     C 100n
                     │           │
                   SGND        AGND
                     │
                  TVS 3V3 ── AGND
```

Sensor supply: `+5V_SENS_A` ou `_B` + retorno `SGND` (mapa no conector, sheet 09).

## Canais (`pinout_v2`)

| Sinal | GPIO | Pino | Rail 5 V | Tipo |
|---|---|-----:|---|---|
| `PRESS_OIL` | `PA2` | 25 | A | ratiométrico |
| `PRESS_FUEL` | `PA3` | 26 | A | ratiométrico |
| `LAMBDA_UA` | `PA4` | 29 | — (CJ125) | RC+TVS só |
| `LAMBDA_UR` | `PA5` | 30 | — (CJ125) | RC+TVS só |
| `EWG_POS` | `PA7` | 32 | A | ratiométrico |
| `APP1` | `PB0` | 35 | **A** | ratiométrico |
| `APP2` | `PB1` | 36 | **B** | ratiométrico (rail ≠ APP1) |
| `TPS1` | `PC0` | 15 | A | ratiométrico |
| `ETB_TPS2` | `PC1` | 16 | **B** | ratiométrico |
| `MAP` | `PC2` | 17 | A | ratiométrico (fc ~1,6 kHz) |
| `VBATT` | `PC3` | 18 | — | divisor VBAT |
| `CLT` | `PC4` | 33 | pull-up → A | NTC → SGND |
| `IAT` | `PC5` | 34 | pull-up → A | NTC → SGND |

13 canais ADC. Knock (`PA5` no doc v1) **não** — `PA5` é `LAMBDA_UR` na v2.

## NTC (CLT / IAT)

```
+5V_SENS_A ── Rpu 2k49 ──┬── Rf 1k ──┬── MCU.PCx
                         │           │
                      J1.NTC      C 100n
                         │           │
                       SGND        AGND
                         │
                      TVS 3V3 ── AGND
```

## VBATT (interno)

```
VBAT ── Rhi 47k ──┬── Rf 1k ──┬── MCU.PC3
                  │           │
               Rlo 10k     C 1µF
                  │           │
                PGND        AGND
```

0–18 V → ~0–3,1 V (`raw × 18000 / 4095` no firmware). RC forte OK (VBATT lenta).

## Componentes (refs sheet)

| Grupo | Refs | Valores |
|---|---|---|
| Ratiométricos ×8 | R100–R131, D10–D17, C20–C27 | 10k / 15k / 1k / TVS / 100n |
| Lambda ×2 | R132–R135, D18–D19, C28–C29 | Rf 1k + C 100n + TVS (sem divisor 5 V) |
| NTC ×2 | R136–R141, D20–D21, C30–C31 | 2k49 / 1k / TVS / 100n |
| VBATT | R142–R144, C32 | 47k / 10k / 1k / 1µF |

## Nets
`MCU.PA2`…`PA5`, `MCU.PA7`, `MCU.PB0`/`PB1`, `MCU.PC0`…`PC5`,  
`J1.*_SIG`, `N_*_DIV`, `+5V_SENS_A`/`_B`, `SGND`, `AGND`, `VBAT`, `PGND`

## Checklist
- [x] Canais = `pinout_v2` (2026-08-08)
- [x] APP1 rail A / APP2 rail B
- [x] Sheet regenerada — ERC **0** (2026-08-08)
- [x] Globals ADC na sheet 11 — netlist **13/13** U1↔canais
- [ ] PN TVS / passivos no BOM
- [ ] Title block formal
- [ ] `+5V_SENS_B` no APP2 (supply no conector; condicionamento partilha SGND)

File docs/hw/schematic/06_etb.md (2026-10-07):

# Sheet 06 — ETB — ⚠️ STALE, descreve o BTS7960

> ⚠️ **Desactualizado (2026-08-07).** A arquitectura v2 substitui o módulo BTS7960 pelo
> **L9960T** (ponte dupla, PWM+DIR+SPI) — o mesmo CI passa a servir **ETB e EWG**, que na
> v1 eram separados (EWG estava diferido). Ver [`../architecture_v2.md`](../architecture_v2.md)
> e `docs/hw/pinout_v2.md` (`ETB_PWM`=`PD12`/TIM4_CH1, `ETB_DIR`=`PD13`, `CS_L9960T`=`PD6`).
>
> **Continua válido:** feedback dual TPS (sheet 05), a rejeição do DRV8701 por não ser
> drop-in **foi explicitamente revertida** — o L9960T tem a mesma forma de 2 pinos (+SPI) e
> foi aceite, o que implica reescrever `etb_driver.cpp` de 3 pinos para 2+SPI (dívida de
> firmware, não escrita).
>
> Redesenhar a topologia abaixo para o L9960T (datasheet ST) quando chegar a vez deste bloco.

## Função (stale — BTS7960, ver banner acima)
Ponte-H do motor da borboleta; feedback TPS no sheet 05.

## Referência
- rusEFI / DBW boards: H-bridge externo, feedback dual TPS.  
- Firmware OpenEMS: PWM + IN1 + IN2, ambos LOW = travagem (`etb_driver`).  
**Adoptamos:** módulo BTS7960 (loops de comutação internos).  
**Adaptamos:** 10 kHz (não 20 kHz); PE5/PE7/PE8.  
**Rejeitamos:** DRV8701 (interface 2 pinos ≠ firmware 3 pinos) sem mudança de SW.

## Topologia

```
MCU.PE5 (TIM15 PWM) ── ETB_PWM  ── BTS7960.PWM (ou RPWM/LPWN conforme módulo)
MCU.PE7             ── ETB_DIR1 ── IN1 / R_EN
MCU.PE8             ── ETB_DIR2 ── IN2 / L_EN

VBAT ── bulk ── BTS7960.VCC
PGND ────────── BTS7960.GND   (retorno próprio ao star — não partilhar SGND)

BTS7960.OUT1 ──┬── J2.ETB_M+ (pin ×2)
BTS7960.OUT2 ──┴── J2.ETB_M− (pin ×2)
```

⚠️ Confirmar pinout do **módulo** concreto (RPWM/LPWM vs PWM+DIR).  
Gate de segurança (procedimento): mola default-closed, corte de energia duro, batente, validar
em bancada antes do motor.

## Componentes
| Ref | Notas |
|-----|---|
| U_etb | BTS7960 module |
| C_bulk | 100–470 µF em VBAT junto do módulo |
| F_etb | fusível dedicado opcional no chicote |

## Nets
`ETB_PWM`, `ETB_DIR1`, `ETB_DIR2`, `ETB_MOTOR_P/N`, `VBAT`, `PGND`

## Checklist
- [ ] 10 kHz no firmware (path etb_driver)  
- [ ] Motor pins duplicados no AMPSEAL 23  
- [ ] Feedback TPS longe do par de potência

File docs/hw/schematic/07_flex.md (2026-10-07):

# Sheet 07 — Flex fuel

## Função
Sensor GM/Continental 50–150 Hz → **`PB4`** (`TIM3_CH1` / captura) — autoridade:
[`../pinout_v2.md`](../pinout_v2.md) (`FLEX_IN`). Duty = temperatura combustível.

⚠️ **Não usar `PB5`.** Um rascunho anterior tinha `MCU.PB5`; o pinout v2 fixa flex em
`PB4` (pino 90). Corrigido 2026-08-07.

## Referência
- Speeduino flex input; rusEFI flex.
- Pull-up ~3k3 onboard no sensor; **pull-up interno MCU insuficiente**.
**Adoptamos:** divisor 10k/3k3 (0–12 V → ~0–3 V) + TVS + pull-up 10k a 5 V se OC.
**Adaptamos:** pino `PB4` (não o EXTI genérico do doc pré-v2).
**Rejeitamos:** alimentar o sensor a 5 V de lógica sem path de 12 V quando o sensor o exige.

## Topologia

```
J1.FLEX_12V ← VBAT (fused se possível)
J1.FLEX_GND ← SGND
J1.FLEX_SIG ── R1 10k ──┬── R2 3k3 ── SGND
                        │
                     Rpu 10k ← +5V_SENS_B (se open-collector)
                        │
                     TVS 3V3 ── AGND
                        │
                     MCU.PB4   (pinout_v2 FLEX_IN)
```

Sem RC agressivo (entrada digital lenta).

## Nets
`N_FLEX_RAW`, `FLEX_DIG`, `MCU.PB4`, `+5V_SENS_B`, `SGND`, `AGND`, `J1.FLEX_*`

## Checklist
- [x] Pino MCU = `PB4` (pinout_v2) — doc + sheet corrigidos (2026-08-07)
- [x] Global `MCU.PB4` na sheet 11 — netlist: U1/90 + flex (2026-08-08)
- [ ] 12 V sensor separado do rail de lógica
- [ ] Divisor dimensionado a 12 V + margem TVS
- [ ] Sheet com title_block + ERC local limpo (qualidade profissional)

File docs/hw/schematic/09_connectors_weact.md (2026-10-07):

# Sheet 09 — Conectores AMPSEAL + socket WeAct

> ⚠️ **Parcialmente stale (2026-08-07).** Escrito quando a board podia levar o coreboard
> WeAct em headers. A decisão fechada é **H562 soldado** — o WeAct é *só bancada de
> firmware*. Na board nova (`hardware/openems_v1/`) a sheet chama-se `09_connectors` e o
> MCU tem sheet própria, a `11_mcu_h562`.
>
> **Continua válido:** J1/J2 AMPSEAL RA, test points, star GND.
> **Ignorar:** tudo sobre socket/headers dual-row do WeAct.
>
> 🚫 **Bloqueado:** o footprint do AMPSEAL **23 vias** não existe no repo — ver
> [`../ampseal_connectors.md`](../ampseal_connectors.md).

## Função
Fronteira mecânica/eléctrica: J1/J2 AMPSEAL RA, headers dual-row WeAct, TP, star GND.

## Referência
- `../ampseal_connectors.md`, `../weact_h562_coreboard.md`, `../weact_h562_schematic.md`  
**Adoptamos:** 35+23 tamanhos diferentes; RA gold; WeAct V1.0 38,62×69,10 mm.  
**Rejeitamos:** +12 V bobina/inj no conector da ECU.

## J2 — 23-pos potência (`1-770669-1` / plug `770680-1`)

| Pos lógicas | Net |
|---|-----|
| 1–2 | VBAT+ |
| 3–5 | PGND |
| 6–9 | INJ1–4 LS |
| 10–13 | IGN1–4 trigger |
| 14–15 | VVT_EXH / VVT_INT |
| 16–18 | PUMP_RLY / FAN_RLY / MAIN_RLY (DNP) |
| 19–20 | ETB_MOTOR_P ×2 |
| 21–22 | ETB_MOTOR_N ×2 |
| 23 | livre |

## J1 — 35-pos sinais (`1-776180-1` / plug `776164-1`)

| Grupo | Nets |
|---|---|
| CKP | CKP_P, CKP_N, CKP_SHLD |
| CMP | CMP_SIG, CMP_5V, CMP_GND |
| Analógicos | MAP, CLT, IAT, APP1, APP2, FUEL_P, OIL_P, ETB_TPS1/2 |
| Rails | +5V_SENS_A/B, SGND×2 |
| CAN | CANH, CANL, CAN_SHLD |
| Flex | FLEX_12V, FLEX_SIG, FLEX_GND |
| Reserva | KNOCK×2, CMP2×3, TPS_INDEP, livres |

⚠️ Cavidades físicas 1…N: mapear após orientação pin 1 do header (drawing TE).

## WeAct P1/P2
Dual-row 2,54 mm; nets em `weact_h562_schematic.md`.  
Furos Φ3,2 @ offset 2,80 mm.

## Star ground
Único ponto: PGND + SGND + AGND + SHIELD_GND.  
Correntes INJ/IGN/ETB **nunca** atravessam SGND/AGND.

## Checklist
- [ ] Footprints TE das páginas de layout  
- [ ] Pin 1 silk + key color black  
- [ ] WeAct pin 1 confere com silkscreen físico

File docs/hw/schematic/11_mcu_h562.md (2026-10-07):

# Sheet 11 — MCU STM32H562VGT6 (LQFP100, soldado)

## Função
O MCU em si: alimentação (VDD/VSS/VDDA/VSSA/VCAP/VBAT/VDDUSB), cristal HSE, reset,
strapping de boot, SWD. É a sheet de que **todos os outros blocos dependem para ter
pinos** — nenhuma outra sheet deve desenhar-se antes desta.

Diferença chave para o fork mRE: lá o MCU vinha **soldado numa board de terceiros**
(coreboard ou o próprio microRusEFI), e a decoupling de bordo já vinha resolvida. Aqui o
H562 é **soldado nesta placa** — toda a decoupling é responsabilidade desta sheet, não
há coreboard a assumir nada por baixo.

## Referência (Speeduino / rusEFI)

- **rusEFI**, `hardware/vendor/hw_microRusEfi/stm32.kicad_sch` (sheet `stm32f407_board`
  — é F407, não H5, mas mesma família ST e mesma filosofia de decoupling):
  VCAP 2× **2,2 µF**; ~9× **100 nF** por pino VDD + **1 µF** bulk; cristal HSE
  **8 MHz / 20 pF** de especificação, com **2× 18 pF** 0603 como caps de carga
  montados; SWD via **Tag-Connect TC2030-IDC-NL 2×3** (`Connector:Tag-Connect_TC2030-IDC-NL_2x03_P1.27mm_Vertical`).
- **rusEFI, LSE**: expõe `Y2` 32 768 Hz (`Crystal_SMD_3215-2Pin_3.2x1.5mm`) para RTC —
  **não adoptado**, ver Rejeitamos.
- **Speeduino**: suporte STM32 é só firmware (`board_stm32_official.cpp/h`); **sem
  esquemático de hardware STM32 no repo local** — nada a adoptar deste lado para este
  bloco especificamente.
- **WeAct H562VGT6 V1.0** (`docs/hw/stm32h562_ref.md` §3.1) — board real, mesmo chip
  exacto que o nosso, roda o firmware de bancada hoje: confirma **VCAP 2× 2,2 µF X7R**
  independentemente do rusEFI, e confirma **HSE = 8 MHz**.
- **WeAct H562VGT6 V1.0, schematic PDF** (`docs/hw/weact_h562_v10_schdoc.pdf`, lido
  directamente — o mesmo ficheiro já citado acima, agora ao nível do cristal): o HSE do
  board deles (nos pinos `PH0-OSC_IN`/`PH1-OSC_OUT`, referenciado como `X2` no PDF deles
  — não confundir com o `X1` que adoptamos abaixo, é a *ref* deles, não a nossa) está
  rotulado **"8MHz-10 pF ±10 ppm"** — CL **10 pF**, não os 20 pF do rusEFI — com caps de
  carga **12 pF / 12 pF** medidos no board real. (O cristal `XTAL3225` desse mesmo PDF,
  referenciado `X1` por eles, é o de **32,768 kHz** do RTC, caps 10 pF/10 pF — não usado
  aqui, ver Rejeitamos.)
- **JLCPCB/LCSC** (catálogo, não datasheet completo — ver ressalva abaixo): parte real
  disponível, `Suzhou Liming Elec 3225-8.00-10-10-10/A` (JLCPCB/LCSC `C518154`),
  8 MHz, **CL = 10 pF**, tolerância ±10 ppm, footprint `SMD3225-4P` — bate certo com o
  CL medido no WeAct.
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

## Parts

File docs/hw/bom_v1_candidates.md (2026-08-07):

# BOM v1 — candidatos (não fecha compra)

Critério do plano: desempenho / imunidade a ruído, não preço mínimo.  
**Part numbers a validar stock/preço antes de pedido.**

---

## Já fechados por decisão

| Função | PN / tipo | Notas |
|---|---|---|
| MCU module | WeAct **H562 VGT6** CoreBoard V1.0 | 38,62×69,10 mm |
| Power stage IC | **TLE8888-2QK** LQFP-100 | WD off; pinout `tle8888_pinout.md` |
| ETB H-bridge | **BTS7960** module @ 10 kHz | 3 pinos PWM+IN1+IN2 |
| Plug sinais | **776164-1** | 35-pos black |
| Plug potência | **770680-1** | 23-pos black |
| Header PCB 35 | **1-776180-1** (RA gold) | ou tin `776180-1` |
| Header PCB 23 | **1-770669-1** (RA gold) | ETB / corrente |
| Crimp | **770520-*** / **770854** | ver amp table |
| TVS bat | **SMBJ24CA** | plano |
| Fusível entrada | 30 A | plano |

---

## Candidatos (Tier C)

| Função | Candidato | Porquê / alternativa |
|---|---|---|
| Buck ≥500 kHz | **TPS54302** (ou similar automotive) | Plano rejeita LM2596; ripple baixo |
| LDO 3,3 V low-noise | **TPS7A20** / **ADP7118** / **LT1763** class | Rejeita AMS1117; high PSRR em f_sw do buck |
| USB isolator | **ADuM3160** / **ISOUSB211** | Full-speed CDC; + DC-DC isolado lado host |
| DC-DC isolado USB | **B0505S-1W** class ou **NME0505** | Corrente CDC; barreira sem pour de terra |
| P-MOSFET reverse | automotive logic-level P-FET | + fuse 30 A |
| ETB module | BTS7960B board (mercado) | Confirmar pinout RPWM/LPWM vs PWM+IN1+IN2 |
| Hall CMP | open-collector 5 V | polaridade page0[258] bit1 |
| VR CKP | sensor VR 60-2 | TLE VRIN1/2 directo |
| Injectors | high-Z only | OUT1–4 2,2 A class |
| Coils | **IGBT smart** ou bobina + IGBT | IGN = 20 mA gate drive **não** é 5 V TTL garantido |
| Caixa | Hammond 1455 / die-cast catálogo | Cabine; outline após aresta ≥125 mm |

---

## VREF+ (MCU) — ✅ reconfirmado

STM32H562 **LQFP100**: **VREF+ é pino separado** (ex. pin 21 no pinout DS; ver
`stm32h562vg.pdf` Fig. 8). Opção (a) do plano: ligar a **VDDA filtrado**.  
(Em packages onde VREF+ está double-bonded a VDDA, VREFBUF fica limitado — não é o
caso do LQFP100 alvo.)

---

## Ordem de compra sugerida (bring-up)

1. WeAct VGT6 + cabos header 2,54  
2. TLE8888-2QK + pasta/reflow ou proto adapter se houver  
3. AMPSEAL 35+23 plugs + headers RA gold + crimp kit  
4. BTS7960 module + dummy injectors/coils  
5. Buck + LDO + TVS + bulk  
6. Isolador USB + DC-DC isolado

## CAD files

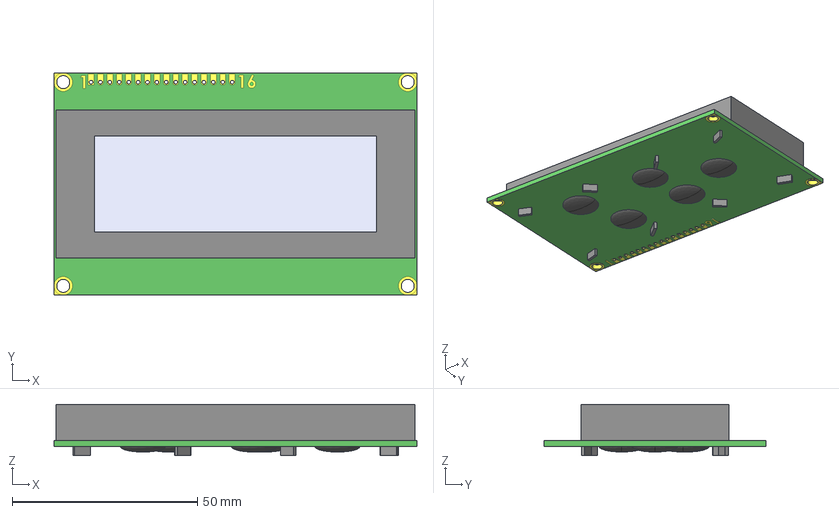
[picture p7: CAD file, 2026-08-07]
hardware/openems_ecu/rusefi_lib_external/3d/LCD_20x4.step
98.0 x 60.0 x 13.9 mm

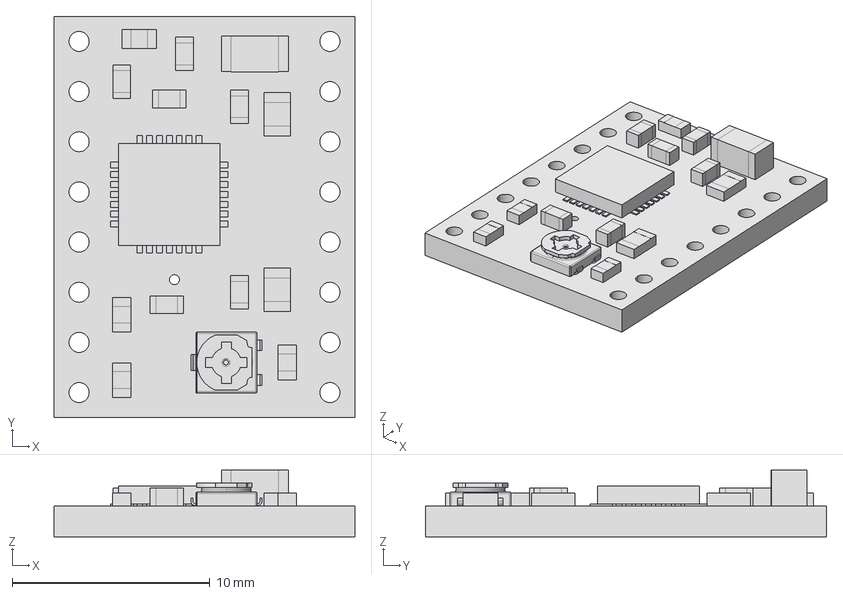
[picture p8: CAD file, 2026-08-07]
hardware/openems_ecu/rusefi_lib_external/3d/Misc/a4988-stepper-motor-driver-carrier.FCStd
15.2 x 20.3 x 3.37 mm

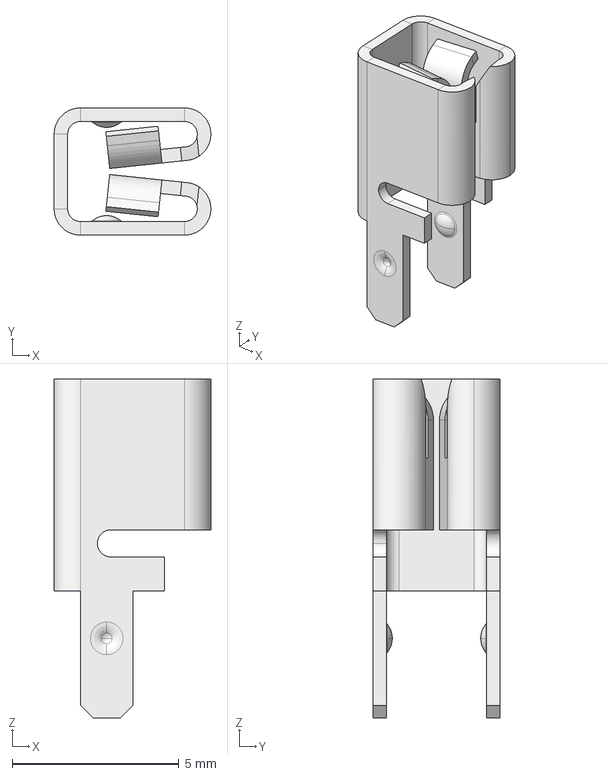
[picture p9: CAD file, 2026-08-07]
hardware/openems_ecu/rusefi_lib_external/3d/keystone-3557.step
4.70 x 3.81 x 10.2 mm

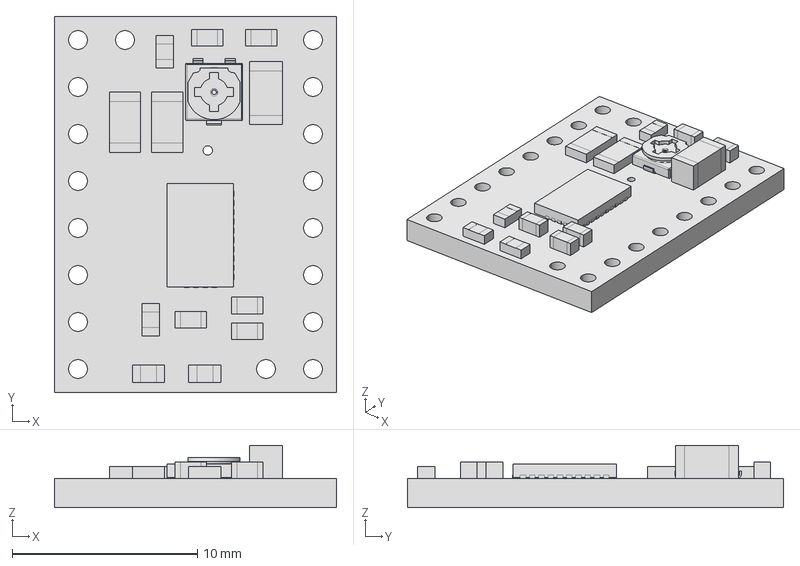
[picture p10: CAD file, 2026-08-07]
hardware/openems_ecu/rusefi_lib_external/3d/Misc/drv8880-stepper-motor-driver-carrier.FCStd
15.2 x 20.3 x 3.37 mm

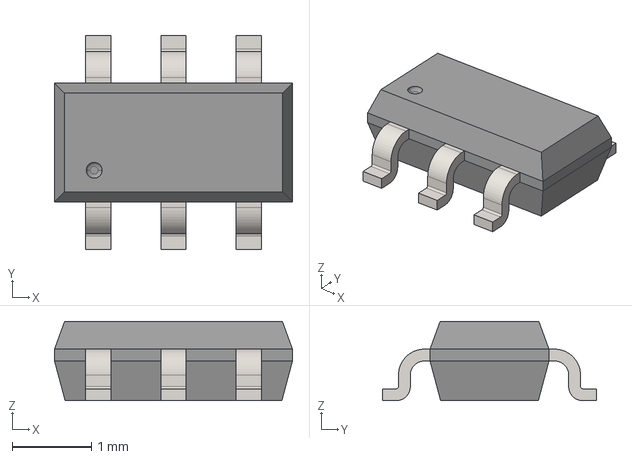
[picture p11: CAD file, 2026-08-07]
hardware/openems_ecu/rusefi_lib_external/3d/TSOP-6.step
3.00 x 2.70 x 1.00 mm

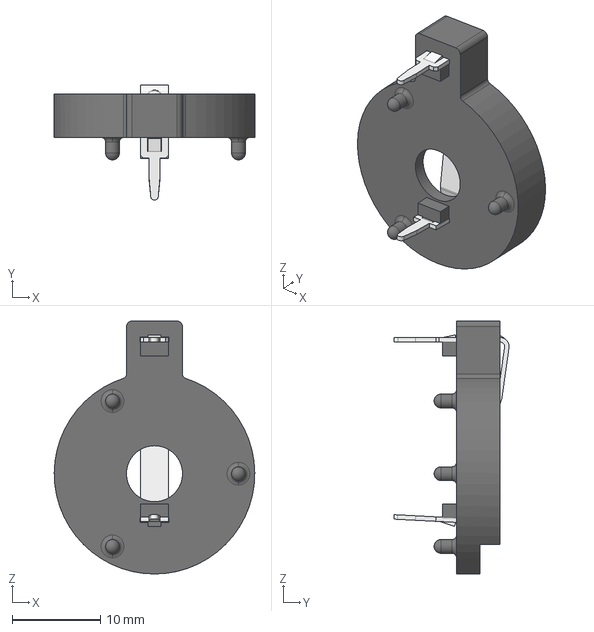
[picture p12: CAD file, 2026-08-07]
hardware/openems_ecu/rusefi_lib_external/3d/MPD_CR2032.STEP
22.8 x 13.1 x 28.7 mm

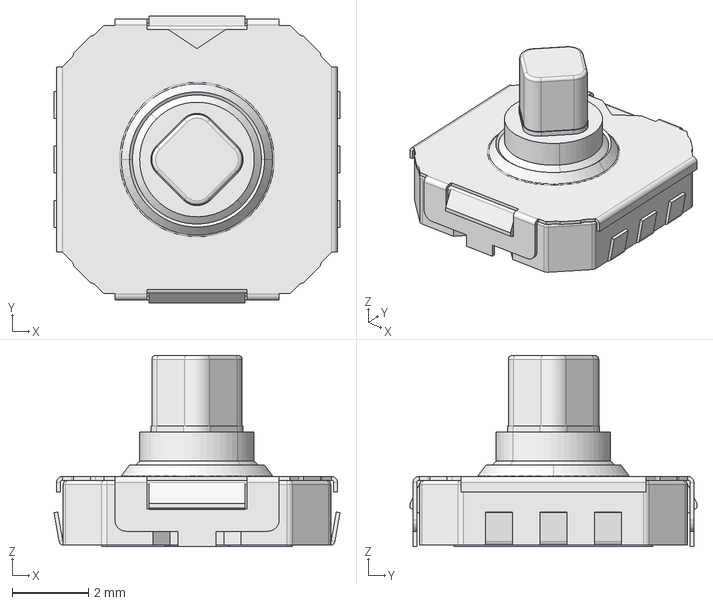
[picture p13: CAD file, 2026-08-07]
hardware/openems_ecu/rusefi_lib_external/3d/JoyStick_SKRHAA.step
7.48 x 7.50 x 5.00 mm

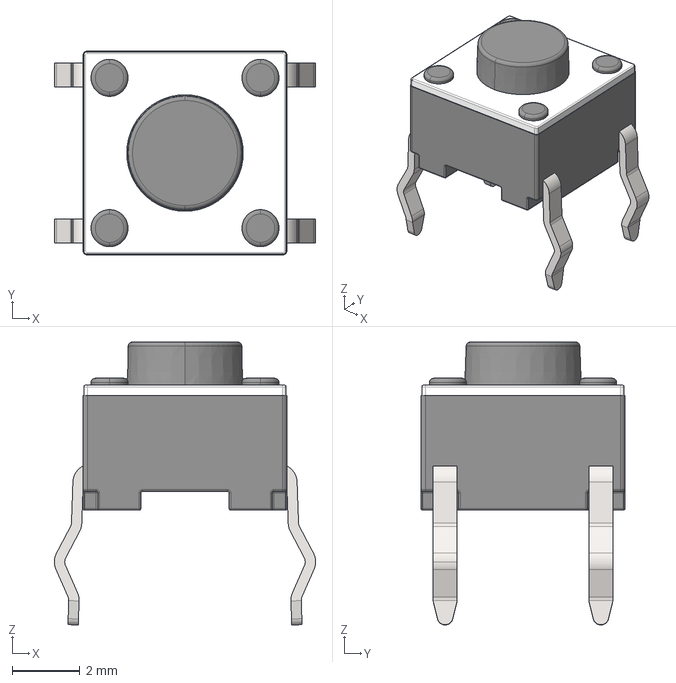
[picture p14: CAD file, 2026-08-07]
hardware/openems_ecu/rusefi_lib_external/3d/tactileswitch-short.step
7.69 x 6.01 x 8.33 mm

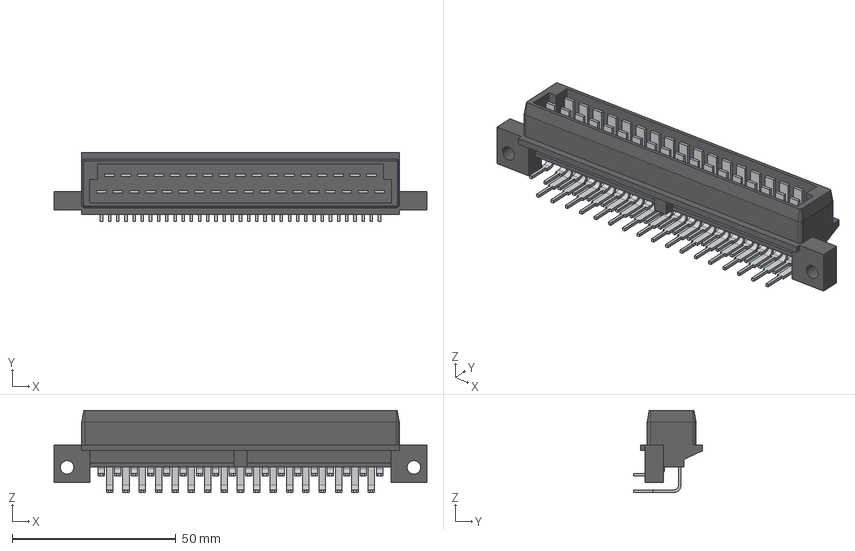
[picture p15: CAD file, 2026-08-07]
hardware/openems_ecu/rusefi_lib_external/3d/c-0825213-01-l-3d.step
114.0 x 21.2 x 25.1 mm

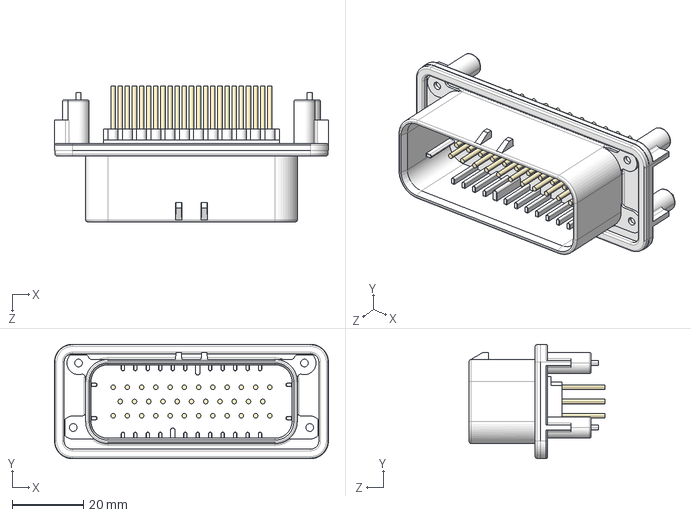
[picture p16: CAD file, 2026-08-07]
hardware/openems_ecu/rusefi_lib_external/3d/c-1-776231-2-d-3d.STEP
76.9 x 32.1 x 38.0 mm

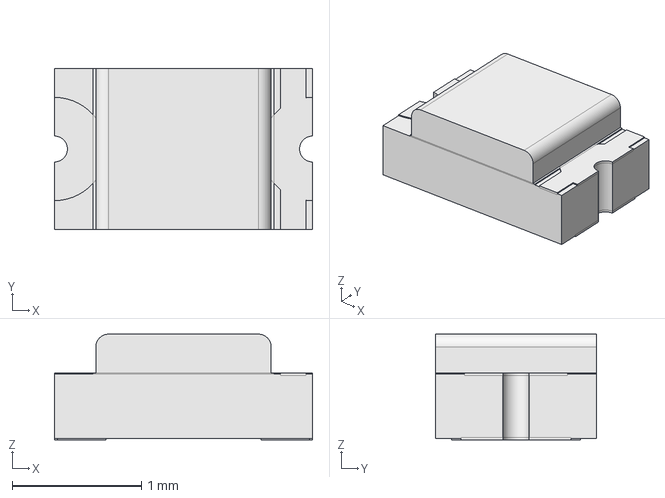
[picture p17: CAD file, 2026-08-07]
hardware/openems_ecu/rusefi_lib_external/3d/LED_0805.step
2.00 x 1.25 x 0.82 mm

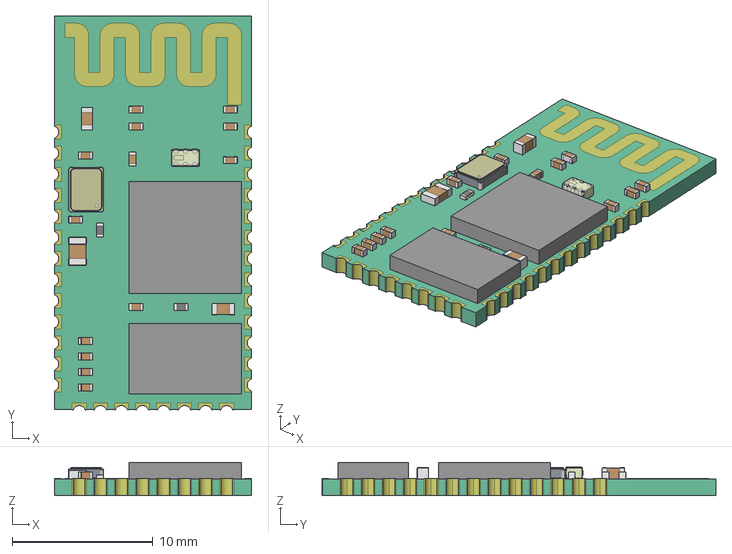
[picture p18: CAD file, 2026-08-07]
hardware/openems_ecu/rusefi_lib_external/3d/itead_hc-05.step
14.0 x 28.0 x 2.35 mm

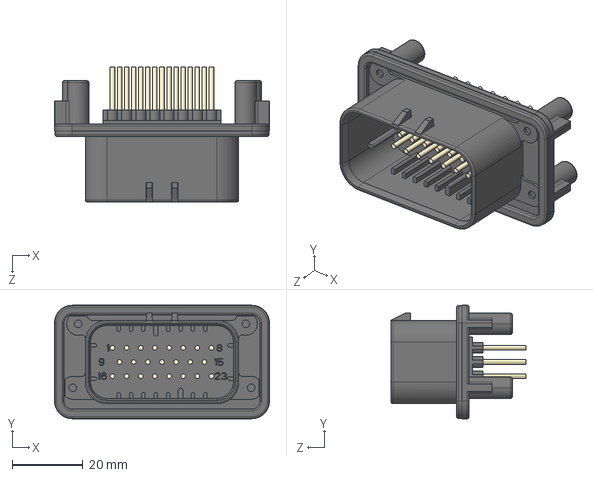
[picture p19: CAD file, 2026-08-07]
hardware/openems_ecu/rusefi_lib_external/3d/c-1-776228-1-e-3d.STEP
60.8 x 32.1 x 38.1 mm

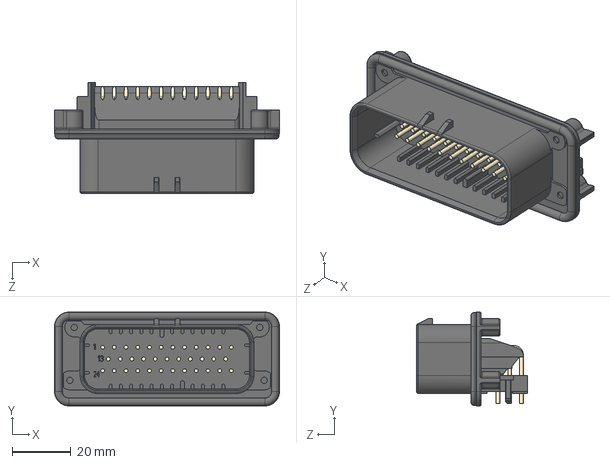
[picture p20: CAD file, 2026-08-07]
hardware/openems_ecu/rusefi_lib_external/3d/AMPSEAL_35_RIGHT_ANGLE.STEP
76.9 x 32.1 x 37.8 mm

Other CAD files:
hardware/openems_ecu/rusefi_lib_external/3d/AMPSEAL_35_STRAIGHT.STEP
hardware/openems_ecu/rusefi_lib_external/3d/BatHolder_SMTU2032.step
hardware/openems_ecu/rusefi_lib_external/3d/HC18U.step
hardware/openems_ecu/rusefi_lib_external/3d/7-5174385-5.stp
hardware/openems_ecu/rusefi_lib/3d/5007620481.stp
hardware/openems_ecu/rusefi_lib_external/3d/AMPSEAL_23_STRAIGHT.stp
hardware/openems_ecu/rusefi_lib_external/3d/LCD_20x4.FCStd
hardware/openems_ecu/rusefi_lib_external/3d/MPD_CR2032.FCStd
hardware/openems_ecu/rusefi_lib_external/3d/Misc/a4988-stepper-motor-driver-carrier.stl
hardware/openems_ecu/rusefi_lib_external/3d/Misc/drv8880-stepper-motor-driver-carrier.stl
hardware/openems_ecu/rusefi_lib_external/3d/TCPL_CONNECTOR_PCC-SMP.step
hardware/openems_ecu/rusefi_lib_external/3d/USB_Vert_C-1734753-1.step
hardware/openems_ecu/rusefi_lib_external/3d/c-1-776231-1-d-3d.STEP
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

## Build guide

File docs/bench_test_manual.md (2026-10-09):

# Manual de teste de bancada — WeAct H562 VGT6

Este manual testa a **lógica do firmware no silício real**: sincronismo, ângulo
da faísca, largura do pulso de injeção, jitter e watchdog. A placa é a WeAct
STM32H562 VGT6 (`docs/hw/weact_h562_coreboard.md`), e o motor é simulado por um
ESP32 com `tools/esp32_combined`.

**O que este teste NÃO prova:** que a ECU dirige bobinas e injetores, que a
fonte e a proteção funcionam, que os sensores reais leem certo. A placa de ECU
ainda não existe (`hardware/openems_v1` só tem o esquemático, incompleto). Por
isso, **não ligue nada de potência** a esta placa: sem bobina, sem injetor, sem
motor. Os pinos de saída vão direto ao ESP32 ou ao osciloscópio, em 3,3 V.

---

## 1. Material

| Item | Uso |
|---|---|
| WeAct STM32H562 **VGT6** (LQFP100) | ECU sob teste |
| ESP32 DevKit (ESP32-WROOM, com DAC) | gerador CKP/CMP 60-2, MAP/TPS, scope lógico |
| Osciloscópio ou analisador lógico, ≥ 4 canais, ≥ 1 MHz | medir ângulo e largura de pulso (T3, T4) |
| Cabo USB-C (DFU e USB CDC) | gravar e comunicar |
| Adaptador USB-serial 3,3 V (opcional) | UART PA9/PA10, se o USB CDC não enumerar |
| Jumpers fêmea-fêmea, GND comum | ligações |
| PC com `arm-none-eabi-gcc`, `dfu-util`, Python ≥ 3.10 | build, gravação, dashboard |

### 1.1 Revisão do chip (errata ES0565)

Antes de tudo, anote a revisão do silício. O README (§ Errata STM32H562 ES0565)
considera a **Rev X**. Na Rev A, PA1 (CMP) só tem histerese quando PA0 está em
entrada, e a flash tem endurance de 1 kciclo.

1. Leia a marcação do chip (a letra de revisão fica na última linha).
2. Conecte em DFU (BOOT0 pressionado + reset) e abra o STM32CubeProgrammer: ele
   mostra `Revision` (campo `REV_ID` de `DBGMCU_IDCODE`).
3. Registre as duas leituras no relatório do teste. Se for Rev A ou Z, pare e
   avise antes de seguir.

---

## 2. Compilar e gravar

```bash
make firmware-vgt6
# saída: /tmp/openems-build/bin/openems-vgt6.bin
```

Gravação por DFU (bootloader de ROM):

1. Segure **BOOT0**, aperte e solte **NRST**, solte BOOT0.
2. `dfu-util -l` deve listar `0483:df11`.
3. Grave:

   ```bash
   dfu-util -a 0 -s 0x08000000 -D /tmp/openems-build/bin/openems-vgt6.bin
   ```

4. Desligue e ligue a placa com BOOT0 solto (BOOT0 = 0).

A calibração fica em setores próprios da flash e sobrevive à gravação do
firmware. Depois de gravar uma versão nova, use **Restaurar padrões de fábrica**
no dashboard (§ 5) para não testar com dados antigos.

---

## 3. Ligações

Pinos do mapa `BOARD=vgt6` (`src/hal/out_pins.h`, `docs/hw/pinout.md`).
Todas as saídas são GPIO ativas em nível alto, acionadas pelo compare do
TIM5_CH3. Repouso = LOW.

| STM32 (WeAct) | Sinal | ESP32 | Observação |
|---|---|---|---|
| PA0 | CKP (TIM5_CH1) | GPIO 2 → | roda 60-2 gerada por RMT |
| — | — | GPIO 2 → GPIO 34 | jumper no próprio ESP32: loopback do CKP para o scope |
| PA1 | CMP (TIM5_CH2) | GPIO 4 → | 1 pulso a cada 720°, no dente 5 |
| PA3 | MAP (ADC) | GPIO 26 → (DAC2) | **obrigatório**: o modo bancada não simula MAP |
| PA4 | TPS (ADC) | GPIO 25 → (DAC1) | **obrigatório**: o modo bancada não simula TPS |
| PE9 | IGN1 | ← GPIO 32 | scope |
| PE11 | IGN2 | ← GPIO 33 | scope |
| PE13 | IGN3 | — | sem entrada livre no ESP32: use o osciloscópio |
| PE15 | IGN4 | — | sem entrada livre no ESP32: use o osciloscópio |
| PE0 | INJ1 | ← GPIO 27 | scope |
| PE2 | INJ2 | ← GPIO 14 | scope |
| PE4 | INJ3 | ← GPIO 12 | scope |
| PE6 | INJ4 | ← GPIO 13 | scope |
| PA9 / PA10 | USART1 TX / RX | — | opcional: adaptador USB-serial, 115200 8N1 |
| USB-C | USB CDC | — | transporte principal do dashboard |
| GND | GND | GND | **obrigatório**, comum a tudo |

Confira a pinagem do ESP32 no cabeçalho de
`tools/esp32_combined/esp32_combined.ino` antes de ligar.

**O que é esperado nesta placa:**

- O LED de heartbeat do firmware é PB2. O LED da WeAct é PC13, então ele **não
  pisca**. Use o dashboard para saber se o firmware está vivo.
- O USB CDC tem driver completo (`src/hal/stm32h562/usb_cdc.cpp`), mas ainda
  não foi validado neste hardware. Se não enumerar (`/dev/ttyACM*` não aparece),
  use a UART PA9/PA10 e anote o problema.

---

## 4. Gerador ESP32 (`tools/esp32_combined`)

1. Copie `wifi_credentials.example.h` para `wifi_credentials.h` (o arquivo é
   ignorado pelo git) e preencha a rede.
2. Compile e grave com PlatformIO (`tools/esp32_combined/platformio.ini`) ou com
   a Arduino IDE.
3. Abra o monitor serial (115200). Comandos principais:

| Comando | Efeito |
|---|---|
| `RPM <n>` | RPM exato (50 a 9000), com rampa ≤ 2 % a cada 50 ms |
| `+` / `-` | RPM ± 100 |
| `0`…`9` | presets 100/200/300/500/700/1000/1500/2000/3000/5000 RPM |
| `IDLE` / `CRANK` / `CRUISE` / `WOT` / `COAST` | presets de RPM + sensores (IDLE = 700, CRANK = 200) |
| `MAP <kPa>` / `TPS <%>` | tensão nos DACs de PA3 / PA4 |
| `S` / `STATUS` | estado do gerador |
| `l` `e` `p` `w` `t` `s` `r` | modos do scope (live, edges, pulsos, waveform, timing, estatística, reset) |

Forma de onda: cada dente é um pulso **alto** de meio período; o gap é o último
dente com o nível baixo estendido em 2 períodos (razão 3). O CMP sobe no dente
5 da primeira volta, 1 µs depois do CKP, para nunca coincidir com ele.
Portanto, a borda útil dos dois é a **subida**.

---

## 5. Dashboard e configuração

```bash
cd tools/openems_dash
python3 -m venv .venv && . .venv/bin/activate
pip install -r requirements.txt
python server.py --port /dev/ttyACM0 --http-port 8000   # ou /dev/ttyUSB0 (UART)
```

Abra `http://localhost:8000`. Na aba **Install**:

1. **Restaurar padrões de fábrica** (com o gerador parado). O tune de fábrica
   (`tools/openems_dash/base_tune.json`) tem offset do gatilho 0, polaridade de
   captura 0 (subida em CKP e CMP) e avanço da lâmpada 10,0°.
2. Passo 2 (CKP/CMP): **deixe as duas caixas de "borda de descida" desmarcadas**.
   O gerador ESP32 é push-pull com dente alto, diferente do Hall open-collector
   do motor real (que usa descida). Polaridade em page0[258]
   (`src/engine/calibration.h:252`).
3. Passo 5 (offset do gatilho): mantenha **0**. Com offset 0, o dente 0 é o PMS
   do cilindro 1, o que torna os ângulos do § 6 fáceis de conferir.
4. Ligue **BENCH** (canto superior). O modo bancada (comando `B`, só RAM, cai no
   reset) simula CLT/IAT/VBATT/óleo/combustível e limpa as falhas desses
   sensores. MAP e TPS continuam reais (PA3/PA4), por isso precisam do ESP32.
   O status bit 15 (`BENCH_MODE`) confirma.

Com o dashboard fechado, o mesmo link serial serve ao script de bancada:

```bash
python3 tools/diag/bench_check.py /dev/ttyACM0 --period 0.5
```

Ele imprime uma linha por leitura (RPM, sincronismo, modo de injeção, confirmações
de CMP, avanço, PW, período do dente, pior loop de 2 ms e os contadores
late/drop/clamp). Termina com `OK` ou `FAIL`, e sai com código 1 se o
`FULL_SYNC` cair depois de alcançado ou se algum contador late/drop/clamp mudar.
O dashboard e o script não podem abrir a porta ao mesmo tempo.

---

## 6. Testes

Registre para cada teste: data, commit do firmware, revisão do chip, resultado
e a captura do osciloscópio quando houver.

### T0 — Boot seguro

1. Osciloscópio em IGN1 e INJ1, gatilho em qualquer borda, modo single.
2. Desligue e ligue a placa 10 vezes, com o gerador **ligado** a 3000 RPM.

**Passa:** nenhuma borda nas saídas durante o boot. As saídas são forçadas a LOW
logo depois do clock (`ecu_sched_outputs_safe_early()`). Sem loop de reset: o
dashboard reconecta e o RPM aparece em poucos segundos.
**Falha:** qualquer pulso no boot, ou a placa reiniciando sozinha. O IWDG tem
~10 s no boot e ~0,8 s em funcionamento (`src/hal/stm32h562/system.cpp:211`,
`src/main_stm32.cpp:385`). Um reset periódico nesses intervalos indica laço
travado.

### T1 — Comunicação

1. Gerador parado. Rode `bench_check.py --count 20`.

**Passa:** 20 linhas, `OK`, sem exceção de CRC ou tamanho. O snapshot tem
**86 bytes** (tabela no § 7).

### T2 — Sincronismo e RPM

1. `RPM 200`, aguarde. Depois suba: 500, 700, 1000, 2000, 3000, 5000, 7000, 8500.
2. Em cada degrau, deixe `bench_check.py` rodando por 30 s.
3. Volte de 8500 até 200 com o comando `-` repetido.

**Passa:**
- O sincronismo vai a `FULL` e lá fica nas subidas e descidas.
- O RPM reportado bate com o do gerador (±1 %), o que confirma o clock de
  62,5 MHz do TIM5.
- O período do dente (`tooth`) vale 1 s ÷ (RPM × 60) — por exemplo,
  1666,7 µs a 600 RPM.
- `late +0 drop +0 clamp +0`, e o script termina com `OK`.

Critérios do decoder (`src/drv/ckp.cpp`): faixas de razão 0,5 e 1,5, e
exatamente 57 dentes entre gaps.

### T3 — Ângulo da faísca (critério principal)

1. Na aba Install, passo 6: **Ligar modo lâmpada** com 10,0°. A faísca fica fixa
   em 10,0° APMS, sem correções nem knock (`src/engine/ign_calc.cpp:76`).
2. Gerador a 1000, 3000 e 6000 RPM, com sincronismo `FULL` e `seq`.
3. Osciloscópio: CH1 = CKP (PA0), CH2 = CMP (PA1), CH3 = IGN1 (PE9),
   CH4 = IGN3 (PE13). Repita com IGN2 (PE11) e IGN4 (PE15).

A faísca é a **borda de descida** da saída IGN (fim do dwell). Com offset 0, a
faísca de cada cilindro cai em `PMS − avanço` (`src/engine/ecu_sched_angle.cpp:113`).
A ordem de ignição é 1-3-4-2, com PMS em 0°/180°/360°/540°
(`src/engine/engine_config.h:51`). Logo:

| Saída | PMS | Faísca a 10° | Onde medir |
|---|---|---|---|
| IGN1 | 0° | 710° | 10° **antes** da subida do dente 0 que fecha a volta com CMP |
| IGN3 | 180° | 170° | 170° **depois** do dente 0 da volta sem CMP |
| IGN4 | 360° | 350° | 10° **antes** da subida do dente 0 que abre a volta com CMP |
| IGN2 | 540° | 530° | 170° **depois** do dente 0 da volta com CMP |

O dente 0 é o primeiro dente depois do gap. A volta que vem depois do pulso de
CMP é a fase A (`src/drv/ckp.cpp:348`), e a fase A começa no ângulo 0. Se
IGN1 e IGN4 aparecerem trocados, anote: é exatamente o tipo de erro que esta
bancada precisa pegar.

Conversão: 1° = T ÷ 6, onde T é o período de um dente. A 3000 RPM, T = 333,3 µs,
então 10° = 555,6 µs e 0,1° = 5,6 µs.

**Passa:** erro ≤ **0,1°** em todos os RPMs, nas quatro saídas.
**Também confira:** o dwell (tempo em HIGH antes da faísca) é estável de ciclo a
ciclo.

Desligue o modo lâmpada ao terminar (ele também cai no reset).

### T4 — Largura do pulso de injeção

**Parte A — pulso de teste (gerador parado, RPM = 0):**
1. Aba **Outputs**: arme o teste (o dashboard manda o keepalive enquanto estiver
   armado). Dispare INJ1 com 1000 µs, 5000 µs e 20000 µs (o máximo é
   30000 µs, `src/engine/output_test.cpp:98`).
2. Meça a largura do pulso em PE0. Repita em INJ2–4.

**Passa:** largura = valor pedido, ±2 µs.

**Parte B — em funcionamento:**
1. Gerador a 3000 RPM, `MAP 60`, sincronismo `FULL` e `seq`.
2. Compare a largura em PE0 com o `pw` do dashboard ou do script (resolução
   0,1 ms).

**Passa:** uma abertura por injetor a cada 720°, uma a cada cilindro, na ordem
1-3-4-2, com largura igual ao `pw` reportado (±0,1 ms).

### T5 — CMP: sequencial e faísca perdida

1. Gerador a 2000 RPM, `FULL` + `seq`, `cmp 2`.
2. Desconecte o fio do CMP (PA1).
3. Depois de ~2 s, reconecte.

**Passa:**
- Sem CMP, o firmware volta para faísca perdida (status bit 11 = 0) e injeção
  semissequencial após 60 voltas no modo bancada. Fora da bancada, são 6
  (`src/drv/ckp.cpp:113`).
- O RPM e o `FULL` continuam.
- Com o CMP de volta, após 2 confirmações (`cmp 2`), o modo volta a `seq`.

### T6 — Perda de CKP

1. Gerador a 3000 RPM, `FULL`.
2. Desconecte o fio do CKP (PA0) com o osciloscópio olhando IGN1 e INJ1.
3. Reconecte.

**Passa:**
- Todas as saídas vão a LOW em poucos ms e ficam em LOW. Nenhuma bobina fica
  presa em dwell.
- O RPM cai para 0.
- Ao reconectar, o firmware passa por `WAIT_GAP` e volta a `FULL` sem reset.

### T7 — Carga e orçamento do loop

1. Gerador a 8500 RPM, dashboard aberto com a aba Telemetry atualizando.
2. Deixe rodar 10 minutos.

**Passa:**
- `loop max` (pior loop de 2 ms) fica bem abaixo de 2000 µs.
- Nenhum contador late/drop/clamp anda.
- Sem reset.

### T8 — Teste de saídas

1. Gerador parado (RPM = 0). O teste de saídas fica bloqueado com o motor
   girando.
2. Na aba Outputs, arme o teste e dispare cada injetor e cada bobina, um de cada vez.

**Passa:**
- Pulso apenas no pino certo (tabela do § 3).
- Dwell da bobina limitado a 10000 µs.
- Sem keepalive por 5 s, o teste aborta e restaura as saídas em LOW
  (`src/engine/output_test.cpp:12`).

### T9 — Reset com o motor girando

1. Gerador a 3000 RPM, `FULL`.
2. Aperte NRST 10 vezes.

**Passa:**
- Nenhum pulso fora de hora nas saídas durante e logo depois do reset.
- O sincronismo volta a cada vez.
- O modo bancada cai (é só RAM), e o dashboard reflete isso pelo status bit 15.

---

## 7. Snapshot de tempo real (86 bytes)

Lido pelo comando `r` da página de tempo real (`OpenEMSLink.read_realtime()`). Os campos de 14 a
65 são `reserved[52]`; o offset do byte é 14 + o índice. Fonte:
`src/app/ui_protocol_pages.cpp` e `tools/openems_dash/protocol.py:116`.

| Byte | Campo | Unidade |
|---|---|---|
| 0–1 | RPM | u16 |
| 2 | MAP | kPa |
| 3 | TPS | % |
| 4 | CLT | °C + 40 |
| 5 | IAT | °C + 40 |
| 6 | lambda | ×1000 ÷ 5 |
| 7 | PW | 0,1 ms |
| 8 | avanço | ° + 40 |
| 9 | VE[0][0] (estático) | — |
| 10 | STFT | % s8 |
| 12–13 | status bits | u16 |
| 14–17 | eventos atrasados (late) | u32 |
| 18 | alvo de lambda | ×1000 ÷ 5 |
| 19 | LTFT | % s8 |
| 20 | glitches de CMP | u8 |
| 21 | confirmações de CMP (0–2) | u8 |
| 22 | reservado | sempre 0 |
| 23 | etanol | % |
| 24–27 | drops do agendador | u32 |
| 28–31 | clamps de calibração | u32 |
| 32 | máscara de rejeição da config | u8 |
| 33 | modo lâmpada ativo | bit 0 |
| 34–35 | avanço enviado às bobinas | 0,1° s16 |
| 36 | reservado | sempre 0 |
| 44 | sync (nibble baixo) / modo de injeção (nibble alto) | 0 WAIT_GAP, 1 HALF, 2 FULL, 3 LOSS / 0 simult., 1 semi, 2 seq |
| 45–46 | redução do controle de tração | 0,1 % |
| 47 | retardo de torque | ° |
| 48 | falhas de sensores | bitmask |
| 49–52 | loop de 2 ms, último | µs u32 |
| 53–56 | loop de 2 ms, máximo | µs u32 |
| 57–62, 64–65 | AN1–AN4 brutos | u16 |
| 63 | **VE ao vivo** | — |
| 66–67 | MAP fundido | kPa ×1 (bar×100) |
| 68–69 | PW líquido | µs |
| 70–73 | bordas CKP | u32 |
| 74–77 | bordas CMP | u32 |
| 78–81 | período do dente | ns u32 |
| 82–83 | idade da última borda CKP | ms |
| 84–85 | idade da última borda CMP | ms |

**Status bits** (`src/app/status_bits.h`):

| Bit | Nome | Bit | Nome |
|---|---|---|---|
| 0 | FULL_SYNC | 8 | SCHED_CLAMP |
| 1 | PHASE_A | 9 | WBO2_FAULT |
| 2 | SENSOR_FAULT | 10 | reservado (sempre 0) |
| 3 | LIMP_MODE | 11 | IGN_SEQUENTIAL (0 = faísca perdida) |
| 4 | ETB_LIMP | 12 | REV_LIMIT |
| 5 | XTAU_LEARN | 13 | LAUNCH_ACTIVE |
| 6 | SCHED_LATE | 14 | TC_ACTIVE |
| 7 | SCHED_DROP | 15 | BENCH_MODE |

---

## 8. Problemas comuns

| Sintoma | Causa provável |
|---|---|
| `/dev/ttyACM*` não aparece | USB CDC não enumerou: use a UART PA9/PA10 (`--port /dev/ttyUSB0`) e anote |
| `dfu-util` não acha a placa | BOOT0 não estava pressionado no reset; cabo só de carga |
| RPM 0 com o gerador ligado | GND não comum; fio em PA0 errado; polaridade "descida" marcada |
| Sincronismo oscila entre `WAIT_GAP` e `FULL` | gerador abaixo de 200 RPM; ruído no fio do CKP (encurte, torça com GND) |
| Fica em faísca perdida com CMP ligado | `cmp` não chega a 2: CMP em PA1 solto, ou polaridade CMP "descida" marcada |
| `SENSOR_FAULT` aceso | modo bancada desligado, ou MAP/TPS (PA3/PA4) sem os DACs do ESP32 |
| Teste de saídas recusado | RPM > 0: desligue o fio do CKP |
| Ângulo errado por um múltiplo de 6° | offset do gatilho ≠ 0; confira na aba Install |
| Ângulo errado por 360° (IGN1 ↔ IGN4) | fase invertida: relate com a captura CKP + CMP + IGN1 |
| `late`/`drop` sobem em RPM alto | relate com RPM e `loop max`: é bug do agendador |

---

## 9. Antes do primeiro motor

Esta bancada é a primeira de várias etapas. Antes de girar um motor:

- [ ] T0–T9 aprovados nesta placa, com as capturas arquivadas.
- [ ] Revisão do chip registrada (§ 1.1).
- [ ] **Placa de ECU projetada, fabricada e testada**: fonte, drivers de
      injetor e bobina, condicionamento de CKP/CMP, proteção. **Ainda não
      existe.**
- [ ] Repetir T0, T3, T4 e T6 na placa de ECU, com carga resistiva no lugar
      das bobinas e dos injetores.
- [ ] Os 10 passos de instalação do README feitos no motor: polaridade
      descendente para Hall open-collector, offset medido, dead time do
      injetor e confirmação com a lâmpada de ponto.

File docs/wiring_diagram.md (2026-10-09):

# OpenEMS — Esquemático Elétrico

> ⛔ **Documento histórico.** O TLE8888 não é usado nesta ECU: o driver foi removido do firmware e as saídas INJ/IGN saem direto por GPIO. Mantido só como referência.

> **Âmbito deste ficheiro:** alimentação, condicionamento de sinal, atuadores externos,
> **conector** e terra. É o que não cabe no mapa de pinos.
>
> **NÃO é fonte de pinout, de registadores nem de capacidade de saída.** Essas vivem em:
> | O quê | Onde |
> |---|---|
> | Mapa de pinos (RGT6 vs VGT6) | `docs/hw/pinout.md` |
> | INJ/IGN, enables, BSRR | `src/hal/out_pins.h` |
> | Registadores do TLE8888 | `src/hal/tle8888_regs.h` (verificado vs Rev 1.2) |
> | Arquitetura da placa, blocos, BOM | `docs/hw/interface_board_v1.md` |
>
> ⚠️ **Porque esta separação é levada a sério:** a versão anterior deste ficheiro
> continha um mapa de pinos ASCII (INJ em TIM2, IGN em TIM8) e uma descrição dos
> registadores/capacidades do TLE8888 — **ambos inventados**. Essa narrativa
> propagou-se para `src/hal/tle8888.cpp`, que ficou escrito contra um mapa de
> registadores inexistente e teve de ser reescrito de raiz. Autoridade duplicada não
> se mantém sincronizada à mão. **Não repor aqui detalhe de pino ou de registador.**

Alvo da placa de interface v1: **STM32H562VGT6 (LQFP100)** + **TLE8888-2QK** como hub de
potência. INJ/IGN por *direct drive* (GPIO → IN1–IN8 do CI), sem MOSFETs discretos.

---

## Alimentação

```
                    ┌─────────────────────────────────────────────────┐
                    │              DISTRIBUIÇÃO DE POTÊNCIA           │
                    │                                                 │
  Bateria 12V ──►──┤ P-MOSFET (proteção de polaridade invertida)     │
                    │    │                                            │
                    │  Fusível 30A                                    │
                    │    │                                            │
                    │  Relé principal (driver integrado no TLE8888)   │
                    │    │                                            │
                    │    ├── rail VBAT ──────────────────────────────│
                    │    │    ├── TLE8888 VBAT (100µF + 100nF)       │
                    │    │    ├── Relé da bomba (fusível 15A)        │
                    │    │    ├── WBO2 (fusível 5A)                  │
                    │    │    ├── Sensor flex fuel 12V               │
                    │    │    ├── Solenóides VVT                     │
                    │    │    ├── SMBJ24CA TVS no rail VBAT          │
                    │    │    └── divisor 0–18V ──► PC3 (VBATT ADC)  │
                    │    │                                            │
                    │    ├── 5V dos sensores: TRACKERS do TLE8888    │
                    │    │    (DVT5Vx, ±10 mV — feitos para sensor   │
                    │    │     ratiométrico; substituem o buck aqui) │
                    │    │    ├── MAP, TPS, APP1/2                   │
                    │    │    ├── P. combustível, P. óleo            │
                    │    │    ├── pull-ups NTC (CLT, IAT)            │
                    │    │    ├── ETB TPS1/TPS2                      │
                    │    │    └── pull-up do flex fuel               │
                    │    │                                            │
                    │    └── LDO 3.3V para o MCU                     │
                    │         ├── STM32 VDD (100nF por pino VDD)     │
                    │         ├── STM32 VDDA (ferrite + 1µF + 100nF) │
                    │         └── VREF+ (pino separado — só LQFP100) │
                    │                                                 │
                    └─────────────────────────────────────────────────┘
```

⚠️ **Peças do desenho legado explicitamente rejeitadas** (critério de imunidade a ruído):

| Rejeitado | Porquê | Usar |
|---|---|---|
| **LM2596-HV** | 150 kHz, ripple ~150 mV — dos switchers mais ruidosos | TPS54302 ou switcher ≥500 kHz de baixo ripple |
| **AMS1117-3.3** | PSRR fraco em alta frequência — não rejeita o ripple que chega | LDO low-noise / high-PSRR |

As duas trocas **andam juntas**: um LDO bom alimentado com 150 kHz de ripple não salva
os sensores ratiométricos. Ver bloco 1 de `interface_board_v1.md`.

✅ **VREF+ decidido: (a) VDDA 3,3 V filtrado**, com (c) reservado como **DNP**.

O cancelamento ratiométrico de (c) — VREF+ derivado do mesmo 5 V, fazendo `V5` cancelar-se
algebricamente — é real, mas ataca um termo que o firmware já cobre: deriva lenta de
referência é absorvida pelo STFT/LTFT, e TPS/APP/ETB trabalham em **percentagem entre
extremos calibrados** (com o ETB a recalibrar os batentes a cada power-on), onde um erro de
escala comum se cancela sozinho.

⭐ **Os trims absorvem deriva, não absorvem ruído.** O MAP é lido 1×/dente e perturba o
combustível desse ciclo — os trims corrigem a média, não a variância. Por isso o esforço
rende no **LDO high-PSRR + filtragem do VDDA + layout**, não numa referência mais exata.

Bónus: (a) é o que o código já assume, incluindo o `18000` de `vbatt_raw_to_mv()` — zero
rework. Reservar footprint do divisor 5 V→~3,0 V + buffer como DNP mantém (c) disponível
sem respin, se o passo 5 da verificação mostrar que a amplitude é limitante.

⚠️ A afirmação de que o LQFP100 tem VREF+ como **pino separado** vem do plano e **não foi
reconfirmada** (PDFs da ST deram timeout; fontes secundárias divergem). Não afeta (a) — aí o
VREF+ liga ao VDDA filtrado de qualquer modo. **Confirmar na tabela de pinout antes de ir
para (c).**

---

## Condicionamento de sinal

```
Entrada analógica genérica (MAP, TPS, APP1/2, P.combustível, P.óleo):

  Sensor (0.5-4.5V) ──[R1 10k]──┬──[R_filt 1k]──┬──► STM32 ADC (máx 3.3V)
                                 │               │
                               [R2 15k]      [C 100nF]
                                 │               │
                                GND             GND
                                 │
                             [TVS 3.3V]
                                 │
                                GND

NTC (CLT, IAT):

  5V ──[R_pull 2.49kΩ]──┬── NTC para GND
                         │
                    [R1 10k]──┬──[R_filt 1k]──┬──► STM32 ADC
                              │               │
                            [R2 15k]      [C 100nF]
                              │               │
                             GND             GND

VBATT (interno à placa — não gasta pino de conector):

  rail VBAT ──[R1]──┬──[RC generoso]──► PC3 / ADC2_INP13
                     │
                   [R2]        divisor 0–18V → 0–3.3V
                     │         (VBATT é lenta: filtrar forte é grátis e
                    GND         rejeita transientes de bobina)
```

| Sensor | Entrada | Divisor | Faixa ADC | Filtro | Proteção |
|---|---|---|---|---|---|
| MAP | 0.5–4.5V | 10k/15k | 0.3–2.7V | RC 1kΩ+100nF | TVS 3.3V |
| TPS | 0.5–4.5V | 10k/15k | 0.3–2.7V | RC 1kΩ+100nF | TVS 3.3V |
| APP1/APP2 | 0.5–4.5V | 10k/15k | 0.3–2.7V | RC 1kΩ+100nF | TVS 3.3V |
| ETB TPS1/TPS2 | 0.5–4.5V | 10k/15k | 0.3–2.7V | RC 1kΩ+100nF | TVS 3.3V |
| **P. combustível** | 0.5–4.5V | 10k/15k | 0.3–2.7V | RC 1kΩ+100nF | TVS 3.3V |
| **P. óleo** | 0.5–4.5V | 10k/15k | 0.3–2.7V | RC 1kΩ+100nF | TVS 3.3V |
| CLT (NTC) | 0–5V (pull-up) | 10k/15k | 0–3.0V | RC 1kΩ+100nF | TVS 3.3V |
| IAT (NTC) | 0–5V (pull-up) | 10k/15k | 0–3.0V | RC 1kΩ+100nF | TVS 3.3V |
| **VBATT** | 0–18V | ver acima | 0–3.3V | RC generoso | TVS |
| Flex fuel | 0–12V quadrada | 10k/3.3k | 0–3.0V | — | TVS 3.3V |
| ~~Knock~~ | *diferido v2* | — | — | envelope, **não** portadora | — |

⚠️ O RC de 1k+100nF dá fc ≈ 1,6 kHz — confortável para grandezas lentas, mas **verificar
contra a banda desejada de MAP** (tem conteúdo rápido por pulsação de coletor; filtrar
demais atrasa a resposta transitória de carga).

⚠️ **Knock não usa a rede padrão.** O ADC amostra 1×/dente (abaixo de Nyquist para 6–8 kHz),
por isso o front-end tem de entregar **envelope** — bandpass → retificação → integrador,
polarizado em meio-rail. Diferido para a v2; só footprint (TPIC8101) na v1.

---

## CKP / CMP — sync

```
┌─────────────────────────────────────────────────────────────┐
│  CKP (relutor VR, roda 60-2) — interface VR do TLE8888      │
│                                                             │
│  Sensor VR ──► par trançado e blindado ──► VRIN1 / VRIN2   │
│    • clamp de entrada integrado (50 mA) → SEM rede externa  │
│      de resistor série + clamp                              │
│    • zero-crossing com armamento por deteção de pico        │
│    • modo auto adaptativo; diagnóstico de sensor por SPI    │
│  VROUT (PUSH-PULL) ──► PA0 (TIM5_CH1, input capture)       │
│    • sem pull-up externo (não é open-drain)                 │
│    • pull-down interno de PA0 MANTIDO (anti falso-sync)     │
│  Blindagem aterrada SÓ no lado da ECU                       │
│                                                             │
│  Bancada: TP-DIG + jumper 0Ω entre VROUT e PA0 — removido,  │
│  liberta o nó para o estimulador ESP32 injetar digital.     │
│  TP-VR no par diferencial para fonte analógica VR real.     │
└─────────────────────────────────────────────────────────────┘

┌─────────────────────────────────────────────────────────────┐
│  CMP (Hall) — caminho próprio (o CI tem UM canal VR)        │
│                                                             │
│  Hall open-collector ──[pull-up 10k → 5V]──┬── divisor ──► │
│                                             │      PA1      │
│                                          RC leve + clamp    │
│                                                             │
│  ⚠️ ABERTO — decidir antes do esquemático:                  │
│     PA1 tem pull-down interno, que luta contra o pull-up    │
│     externo → trocar para pull-up. MAS Hall open-collector  │
│     idle HIGH/pulso LOW põe o início do dente na borda de   │
│     DESCIDA, e TIM5 captura só SUBIDA (CC2E sem CC2P).      │
│     Trocar só o resistor cronometraria o FIM do pulso.      │
│     Ambas as polaridades passam no gate temporal da ISR →   │
│     o erro sairia como deslocamento angular SILENCIOSO.     │
│     O CKP tem a mesma pergunta (CC1E também é só subida).   │
│     Decidir as duas juntas. Ver interface_board_v1.md.      │
└─────────────────────────────────────────────────────────────┘
```

---

## Atuadores externos

```
┌─────────────────────────────────────────────────────────────┐
│  INJEÇÃO / IGNIÇÃO — TLE8888, direct drive                  │
│                                                             │
│  INJ1–4: GPIO ──► IN1–IN4 ──► OUT1–OUT4                    │
│    low-side 2,2 A → injetores de ALTA IMPEDÂNCIA           │
│    (saturado, sem peak-and-hold)                            │
│    clamp, OC, sobretemperatura e diagnóstico integrados     │
│                                                             │
│  IGN1–4: GPIO ──► IN5–IN8 ──► IGN1–IGN4                    │
│    driver de gate push-pull 20 mA → SMART COILS            │
│    (bobinas com ignitor integrado, entrada lógica)          │
│                                                             │
│  INJEN / IGNEN: enables de HARDWARE dos dois grupos.        │
│    LOW = desabilitado; sobem só se o TLE8888 confirmou      │
│    comunicação E configuração. Corte independente do SPI    │
│    e do escalonador.                                        │
│                                                             │
│  Atribuição IN→OUT é FIXA no silício. Pinos: out_pins.h     │
└─────────────────────────────────────────────────────────────┘

┌─────────────────────────────────────────────────────────────┐
│  ETB — ponte-H EXTERNA: BTS7960 @ 10 kHz (decidido)         │
│                                                             │
│  As meias-pontes do TLE8888 são de só 0,6 A — falta uma     │
│  ordem de grandeza para o motor da borboleta.               │
│                                                             │
│  PWM (TIM15_CH1) ──► BTS7960 PWM    [VGT6: PE5]            │
│  DIR abrir  (GPIO) ──► IN1          [VGT6: PE7]            │
│  DIR fechar (GPIO) ──► IN2          [VGT6: PE8]            │
│    (ambos a 0 = travagem)                                   │
│  ETB TPS1/TPS2 ──► ADC (realimentação de posição)          │
│  12V ──► ponte VCC       GND ──► ponte GND                 │
│                                                             │
│  PWM baixado de 20 kHz para 10 kHz: o BTS7960 vai até       │
│  25 kHz, e a 20 kHz sobravam só 20% de margem com perdas    │
│  de comutação altas (FETs internos, sem como aliviar).      │
│  Custo aceite: chiado audível. A interface de 3 pinos       │
│  (PWM+IN1+IN2) mapeia 1:1 no firmware actual.               │
│                                                             │
│  ⚠️ Sem botão de slew (FETs integrados). Se o ETB acoplar   │
│     ruído no par CKP, os remédios são layout, blindagem e   │
│     filtro. Vigiar no teste de ruído sob carga.             │
│                                                             │
│  ⚠️ GATE DE SEGURANÇA — o ETB é a ÚNICA autoridade sobre a  │
│     borboleta (o IACV foi removido) e o autocal+PID nunca   │
│     correram em hardware. Travado aberto = motor em         │
│     disparada. Exigir: mola default-closed verificada,      │
│     corte de energia duro ao alcance, batente mecânico, e   │
│     validação em bancada ANTES de montar no motor.          │
└─────────────────────────────────────────────────────────────┘

┌─────────────────────────────────────────────────────────────┐
│  VVT — 2 solenóides, TLE8888 OUT5/OUT6                      │
│                                                             │
│  PWM 15 Hz (TIM4_CH1/CH2) ──► IN11/IN12 ──► OUT5/OUT6      │
│    low-side 4,5 A com CLAMP ATIVO 50–60 V                  │
│    → saem da BOM os drivers de solenóide e os diodos de     │
│      roda-livre                                             │
│                                                             │
│  ⚠️ Os DOIS PIDs consomem o MESMO pos_deg_x10, derivado do  │
│     ÚNICO CMP. O came instrumentado fica em malha fechada;  │
│     o outro persegue a posição do came errado. Controlo     │
│     dual real pede 2º sensor de came + firmware.            │
│     v1: montar os dois, comissionar só o instrumentado,     │
│     reservar via no conector para o 2º sensor.              │
└─────────────────────────────────────────────────────────────┘

┌─────────────────────────────────────────────────────────────┐
│  RELÉS — bomba e ventoinha, saídas do TLE8888               │
│                                                             │
│  Saídas de relé (0,6 A — folgado para bobina de ~200 mA)    │
│  + driver de relé principal integrado.                      │
│  → saem da BOM os drivers discretos e os diodos.            │
│                                                             │
│  Bomba: prime 2 s no key-on, mantém com RPM > 0, corta 2 s  │
│  após RPM = 0.  Ventoinha: histerese 95/90 °C.              │
└─────────────────────────────────────────────────────────────┘

┌─────────────────────────────────────────────────────────────┐
│  CAN — transceiver integrado no TLE8888                     │
│                                                             │
│  FDCAN1_TX ──► TXD        FDCAN1_RX ◄── RXD                │
│  CANH/CANL ──► barramento, terminação 120Ω jumpeável        │
│  Sem transceiver externo (TJA1051 sai da BOM).              │
│  Serve WBO2 (RX 0x180) e telemetria (0x400/0x401/0x402).    │
└─────────────────────────────────────────────────────────────┘

┌─────────────────────────────────────────────────────────────┐
│  WBO2 (Bosch CJ125 / AEM 30-0300) — só por CAN             │
│  12V (fusível 5A) · CANH/CANL · sonda LSU 4.9              │
│  Não há ADC de O2.                                          │
└─────────────────────────────────────────────────────────────┘

┌─────────────────────────────────────────────────────────────┐
│  FLEX FUEL (GM / Continental)                               │
│  12V ──► sensor                                             │
│  Sinal ──[R1 10k]──┬──► PB5 (EXTI)                         │
│                 [R2 3.3k]                                    │
│                    GND                                       │
│  Pull-up 10kΩ → 5V se a saída for coletor aberto            │
│  50 Hz = 0% etanol, 150 Hz = 100%                           │
│  Duty 10–90% = -40 a +125 °C de temperatura do combustível  │
│  Onda quadrada lenta — filtrar com folga.                   │
└─────────────────────────────────────────────────────────────┘

┌─────────────────────────────────────────────────────────────┐
│  USB — COM ISOLADOR GALVÂNICO (conector interno)            │
│                                                             │
│  Ligar o laptop com o motor a rodar cria laço de terra      │
│  entre a massa do veículo e a do portátil — matador         │
│  clássico de ECU e injetor de ruído durante a calibração.   │
│  Isolador JUNTO AO CONECTOR, não junto ao MCU.              │
│  Requer alimentação isolada do lado do veículo.             │
└─────────────────────────────────────────────────────────────┘

┌─────────────────────────────────────────────────────────────┐
│  ~~EWG / boost~~ — DIFERIDO para a v2 (só footprint)        │
│  Turbo-específico; o segundo pino DIR ainda é TODO(VGT6).   │
│  É o que libertou PC3 para o VBATT.                         │
│  O canal de realimentação de posição deixou de existir:     │
│  ewg_driver_read_position_raw() devolve 0.                  │
└─────────────────────────────────────────────────────────────┘
```

---

## Conector do chicote — TE AMPSEAL, dois tamanhos

Expresso no que **sai da placa**, não em pinos do MCU. USB e SPI são internos.

**Conector A — `776164-1` (35 vias) = SINAIS · Conector B — `770680-1` (23 vias) = POTÊNCIA**

Tamanhos diferentes são **impossíveis de trocar entre si** — com dois conectores iguais, um
chicote mal ligado é questão de tempo, e aqui isso significa 12 V numa entrada de sensor.
AMPSEAL: 4 mm centerline, 3 filas, IP67, −40…+125 °C, fio 0,5–1,25 mm² (≈20–16 AWG).

| Conector | Grupo | Vias | Sinais |
|---|---|---|---|
| **B** | Potência | 2 | VBAT+ (alimentação da placa) |
| **B** | Potência | 3 | PGND |
| **B** | Injeção | 4 | INJ1–4 low-side (OUT1–OUT4) |
| **B** | Ignição | 4 | IGN1–4 **trigger lógico** (20 mA) |
| **B** | VVT | 2 | escape (LS, OUT5), admissão (LS, OUT6) |
| **B** | Relés | 3 | bobinas: bomba, ventoinha, principal |
| **B** | ETB | 4 | Motor+ ×2, Motor− ×2 (**duplicados** — stall 8–10 A) |
| | | **22/23** | *1 livre* |
| **A** | Sync | 3 | CKP+ (VRIN1), CKP− (VRIN2), blindagem |
| **A** | Sync | 3 | CMP sinal, CMP +5V, CMP GND |
| **A** | Analógicos | 7 | MAP, CLT, IAT, APP1, APP2, P.combustível, P.óleo |
| **A** | ETB | 2 | TPS1, TPS2 |
| **A** | Alimentação de sensor | 4 | 5V_A, 5V_B (trackers), SGND ×2 |
| **A** | CAN | 3 | CANH, CANL, blindagem |
| **A** | Flex fuel | 3 | +12V, sinal, GND |
| **A** | *Knock (diferido)* | 2 | *sinal, blindagem — reservado, NÃO cablar na v1* |
| **A** | Reserva | 8 | 2º came (3), TPS indep. (1), livres (4) |
| | | **35/35** | |

🚨 **Potência de bobinas e injetores NÃO atravessa a ECU.** Bobinas com ignitor integrado só
precisam do trigger lógico; a corrente primária (7–10 A de pico) vem do relé **no chicote** e
nunca deve passar por um contacto de 8 A. Nos injetores, o low-side (~1 A) passa pela ECU mas
o +12 V vem do relé. A tabela anterior levava `+12V bobinas`, `PGND bobinas` e `+12V
injetores` pelo conector — errado, e não só por desperdício de vias.

⚠️ **Motor do ETB é o que esbarra no limite:** ~2–3 A em regime, **8–10 A em stall**, contra
8 A do contacto em estanho (17 A em ouro). Daí os pinos duplicados — ou especificar ouro.

⚠️ **VBATT não gasta via** — mede o rail interno da placa (divisor → `PC3`).

**Regras:** bitola por circuito; pares trançados para CKP/CMP/CAN; blindagens com dreno num
ponto só (lado da ECU); fusíveis por ramo.

**Regras:** separar fisicamente as vias de potência (INJ/IGN/relés/VVT) das de sinal; CKP e
CAN em vias adjacentes com dreno de blindagem; bitola por circuito (injetor e bobina puxam
corrente); pares trançados para CKP/CMP/CAN; fusíveis por ramo.

⚠️ **VBATT não gasta via** — é medida do rail interno da placa (divisor → PC3).

---

## Terra

```
                   Parafuso do chassis (ponto estrela único)
                            │
                 ┌──────────┼──────────┐
                 │          │          │
               PGND       SGND     Shield GND
             (potência)  (sinal)  (blindagens)
                 │          │          │
           ┌─────┤    ┌─────┤    ┌─────┤
           │ TLE8888   │ sensores │ CAN
           │ reguladores│ AGND ADC│ cabo CKP
           │ ponte ETB │ pull-ups │
           │ bomba     │          │
           └───────────┘──────────┘

  Regras de PCB (4 camadas: sinal / TERRA CONTÍNUO / alimentação / sinal):
  • Pours separados PGND / SGND / AGND / Shield, unidos num único ponto.
    Correntes de injetor e bobina NUNCA atravessam o retorno de sinal.
  • Par CKP é a rede mais sensível: curto, blindado, na camada superior sobre
    terra ininterrupto, longe de INJ/IGN/ETB/relés, sem via desnecessária e
    sem passar sob o indutor do buck.
  • Loops de comutação (injetor, bobina, solenóides VVT) fisicamente pequenos
    — área de laço é o que irradia.
  • Cabo de knock é a 2ª rede mais sensível: longe das linhas de bobina e dos
    solenóides VVT — escuta justamente a banda que a ignição emite.
  • 100nF em cada pino VDD; bulk 100µF no estágio de potência; VDDA por ferrite.
  • Blindagens de CKP e CAN aterradas só no lado da ECU.
```

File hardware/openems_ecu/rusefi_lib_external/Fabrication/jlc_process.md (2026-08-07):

See https://github.com/rusefi/hw_modular/tree/master/lowside/gerbers for an example of how things are set.

jlc_prepare-*.bat scripts use grep, gawk & sed so Cygwin is required.

# Bill Of Materials

1) See ../BOM_related file for KiCad to produce XXX.csv KiCad BOM.

1) Use prepare_fabricate.bat to invoke jlc_prepare_bom.bat produce XXX-bom.csv final JLC BOM file.

# Placement

1) Use KiCad to produce XXX-top-pos.csv file

1) Use prepare_fabricate.bat to invoke jlc_prepare_position.bat to produce XXX-cpl.csv final JLC placement file.

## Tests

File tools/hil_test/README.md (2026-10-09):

# OpenEMS HIL Test

Teste automatizado Hardware-in-the-Loop.

## Hardware necessário

```
PC ─ USB ──→ STM32H562 VGT6   (CDC protocolo OpenEMS, /dev/ttyACM0)
PC ─ WiFi ─→ ESP32             (esp32_stimulator, TCP 3333)
   ou USB ─→ ESP32             (/dev/ttyUSB0)
```

Um único ESP32 gera o sinal CKP e (opcionalmente) monitoriza IGN/INJ.

## Ligações (LQFP100 — WeAct STM32H562VGT6)

```
                          CKP / CMP (entrada)
ESP32 GPIO 2  ────────────────→  STM32 PA0   (CKP 60-2, TIM5_CH1)
ESP32 GPIO 4  ────────────────→  STM32 PA1   (CMP, TIM5_CH2)

                          IGN (saída — GPIO, compare TIM5_CH3)
ESP32 GPIO 32 ←────────────────  STM32 PE9   (IGN1)
ESP32 GPIO 33 ←────────────────  STM32 PE11  (IGN2)
              (osciloscópio)     STM32 PE13  (IGN3)
              (osciloscópio)     STM32 PE15  (IGN4)

                          INJ (saída — GPIO, compare TIM5_CH3)
ESP32 GPIO 27 ←────────────────  STM32 PE0   (INJ1)
ESP32 GPIO 14 ←────────────────  STM32 PE2   (INJ2)
ESP32 GPIO 12 ←────────────────  STM32 PE4   (INJ3)
ESP32 GPIO 13 ←────────────────  STM32 PE6   (INJ4)

ESP32 GND     ─────────────────  STM32 GND   (OBRIGATÓRIO)
```

Mínimo para rodar: **CKP (GPIO2→PA0) + GND**. Os demais são opcionais.

## Pré-requisitos

```bash
# Kernel: desabilitar USB autosuspend (causa disconnect da CDC em ~1s)
sudo sh -c 'echo -1 > /sys/module/usbcore/parameters/autosuspend'

# Python
pip install pyserial
```

## Uso

```bash
# Estimulador via WiFi/TCP (recomendado)
python3 hil_test.py --stm32 /dev/ttyACM0 --stim tcp:192.168.15.169:3333

# Estimulador via USB serial
python3 hil_test.py --stm32 /dev/ttyACM0 --stim /dev/ttyUSB0

# Bench sem sensores MAP/TPS (força CLT/IAT, aceita SENSOR_FAULT)
python3 hil_test.py --stm32 /dev/ttyACM0 --stim tcp:192.168.15.169:3333 \
    --bench-clt-iat

# RPMs específicos + relatório
python3 hil_test.py --stm32 /dev/ttyACM0 --stim tcp:192.168.15.169:3333 \
    --bench-clt-iat --rpms 800 1500 3000 --report resultado.md
```

Exit code: `0` se todos PASS, `1` se algum FAIL.

## Flash

```bash
# DFU (sem :leave — fazer power-cycle manual depois)
dfu-util -a 0 -s 0x08000000 -D /tmp/openems-build/bin/openems.bin

# IMPORTANTE: após DFU, power-cycle (despluga/repluga USB com BOOT0 solto).
# O :leave faz jump sem POR — RCC fica no estado do bootloader.
```

## Verificações por ponto de RPM

| # | Verificação | Fonte | Tolerância |
|---|---|---|---|
| 1 | FULL_SYNC atingido | STM32 snapshot | — |
| 2 | Sem sensor fault | STM32 snapshot | — (skip com --bench-clt-iat) |
| 3 | Sem late events | STM32 snapshot | — |
| 4 | RPM medido vs comandado | Snapshot | ±5% |
| 5 | VE snapshot vs tabela Python | Snapshot + page 1 | ±3 |
| 6 | Advance snapshot vs tabela Python | Snapshot + page 2 | ±2° (±8° com limp) |
| 7 | Injection PW vs cálculo | Snapshot + pages 4/5 | ±45% bench / ±15% full |

## Notas bench (sem sensores MAP/TPS)

- `--bench-clt-iat` força CLT=90°C / IAT=25°C via comando 'B' e aceita
  SENSOR_FAULT como esperado (MAP/TPS não conectados leem lixo).
- **Limp rev-cut**: com SENSOR_FAULT, a ECU corta injeção acima de 3000 RPM
  (PW=0 é esperado e o teste aceita automaticamente).
- **PW ~40% acima do calculado**: afterstart enrichment e cranking multiplier
  não são modelados no cálculo Python — tolerância alargada para 45%.
- **Advance limitado em altas RPMs**: limp mode retarda spark perto do rev
  limiter — tolerância alargada para ±8° acima de 3000 RPM com fault.

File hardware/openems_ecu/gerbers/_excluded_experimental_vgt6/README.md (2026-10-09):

# Excluded — experimental VGT6 PCB (do not fab)

Parked at user request (2026-08-04).

These Gerbers / board snapshot came from the **OpenEMS VGT6 PE\* remap +
manual bus routing** experiment on `openems_ecu.kicad_pcb`. High DRC error
count; **not** the production path.

## Active production path (use this)

| | |
|--|--|
| PCB | `hardware/openems_ecu/openems_ecu.kicad_pcb` (= mRE copper + H562 pads) |
| Also | `hardware/openems_ecu/production/openems_mre_h562.kicad_pcb` |
| Gerbers | `hardware/openems_ecu/gerbers/mre_h562/` |
| ZIP | `hardware/openems_ecu/gerbers/openems_mre_h562_*.zip` |
| Firmware | ~~`BOARD=mre`~~ removed; no current firmware build matches this copper (see `docs/hw/README.md`) |
| Pinout | ~~`docs/hw/pinout_mre_bringup.md`~~ (removed) |

## Restore experimental board (if needed)

```bash
cp -a hardware/openems_ecu/openems_ecu.kicad_pcb.bak-experimental-vgt6-* \
      hardware/openems_ecu/openems_ecu.kicad_pcb
```

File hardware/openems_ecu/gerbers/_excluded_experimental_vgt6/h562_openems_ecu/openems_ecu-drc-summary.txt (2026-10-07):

Found 566 violations
Found 50 unconnected items
Saved DRC Report to hardware/openems_ecu/gerbers/h562_openems_ecu/openems_ecu-drc.json

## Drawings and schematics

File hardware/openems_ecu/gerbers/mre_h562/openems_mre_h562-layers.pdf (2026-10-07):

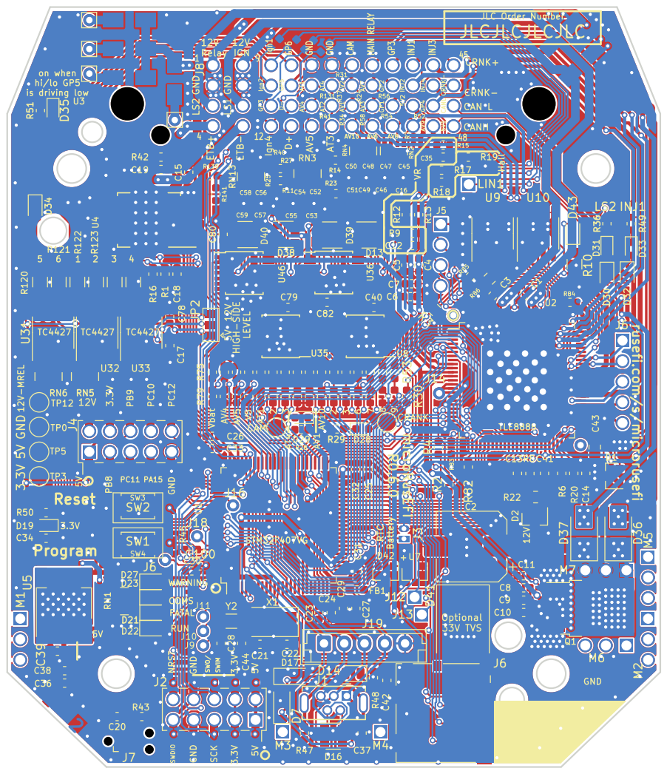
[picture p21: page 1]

JLC Order Number
12 Ign2 GP3 Ign4 Ign1 GP5 D- M3 D+ GP6 AT1 AV4 GND AV5 AT4 AT2 GND AT3 AV2 AV1 CAM
AV6M4GP2 GP1 RTC Battery GP3 J12
J11SWO/ ETB+ SCK SWIM GND LS1 3.3V 3.3V J16ETB-
J9 GND GND GND LS2

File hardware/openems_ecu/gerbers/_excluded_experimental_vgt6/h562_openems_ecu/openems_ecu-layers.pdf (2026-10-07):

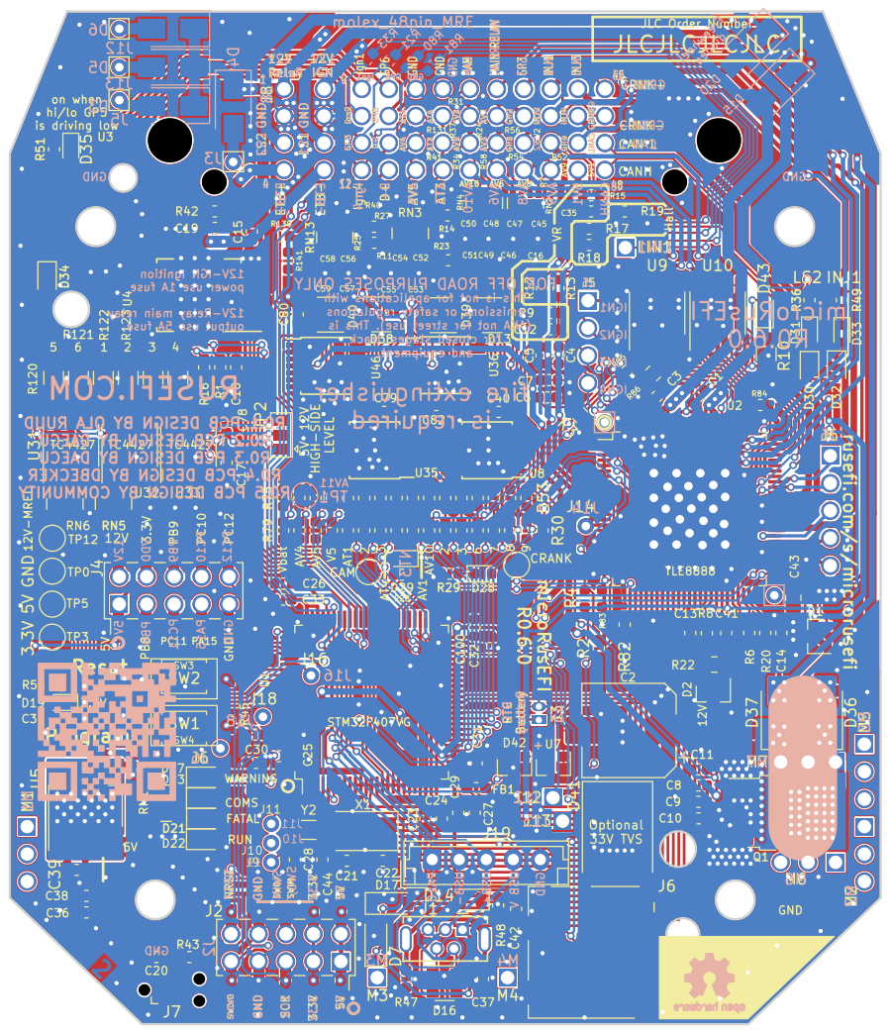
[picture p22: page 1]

Freewheel diodes PA10 USB- USB+ USB V GND RUUD OLA BY DESIGN PCB R0.1 DAECU BY DESIGN PCB R0.2 DAECU BY DESIGN PCB R0.3 DBECKER BY DESIGN PCB R0.4 COMMUNITY BY DESIGN PCB R0.5 extinguisher fire
AV6M4GP2 GP1 RTC Battery GP3 J12
J11SWO/ ETB+ SCK SWIM GND LS1 3.3V 3.3V J16ETB-
J9 GND GND GND LS2

R33 R21 R80 R81 ONLY PURPOSES ROAD OFF FOR with applications for not is This
IGN 5V 5V

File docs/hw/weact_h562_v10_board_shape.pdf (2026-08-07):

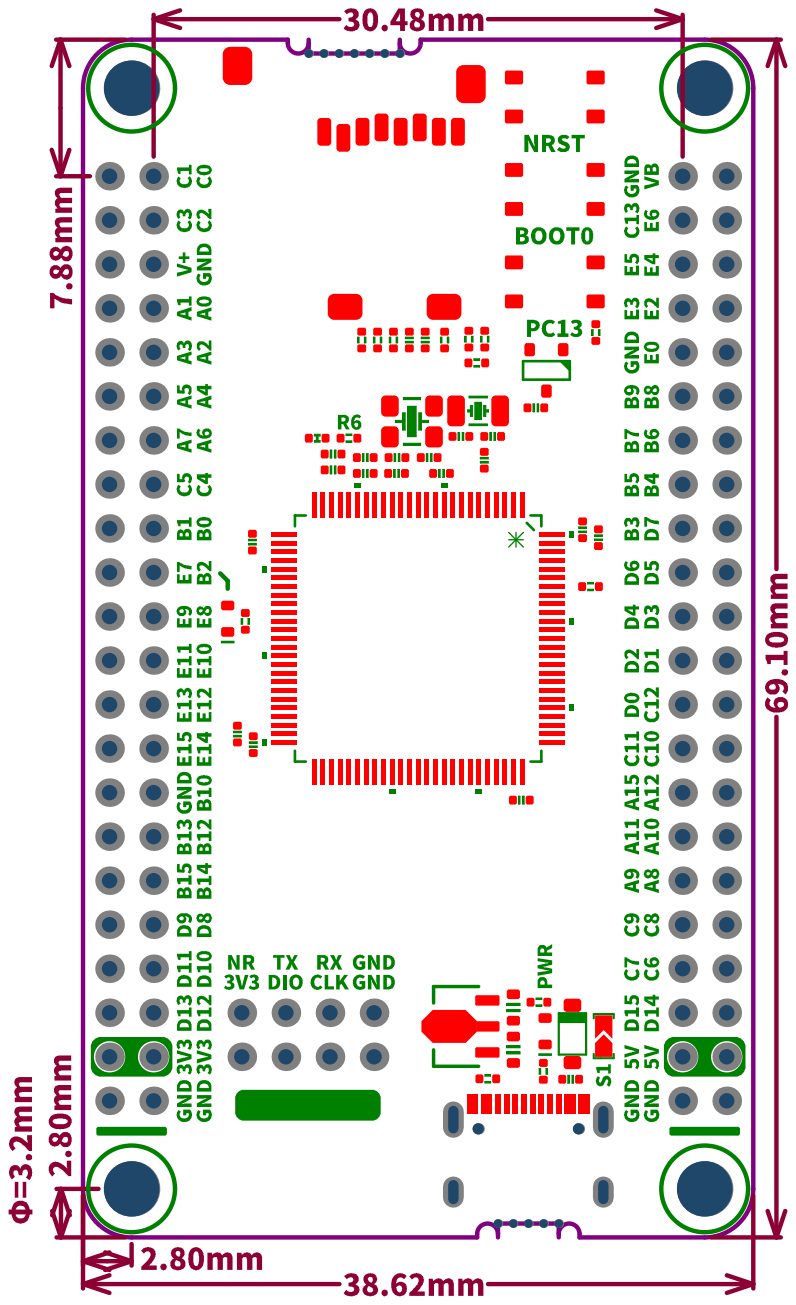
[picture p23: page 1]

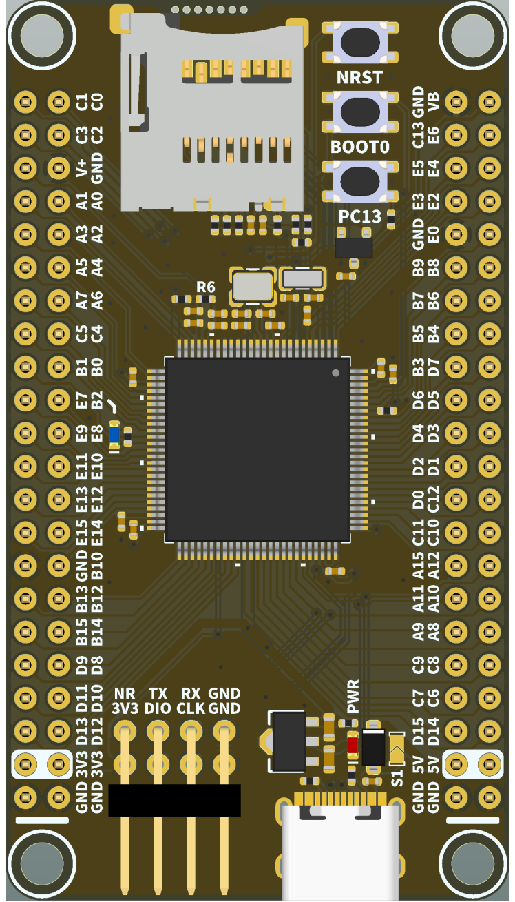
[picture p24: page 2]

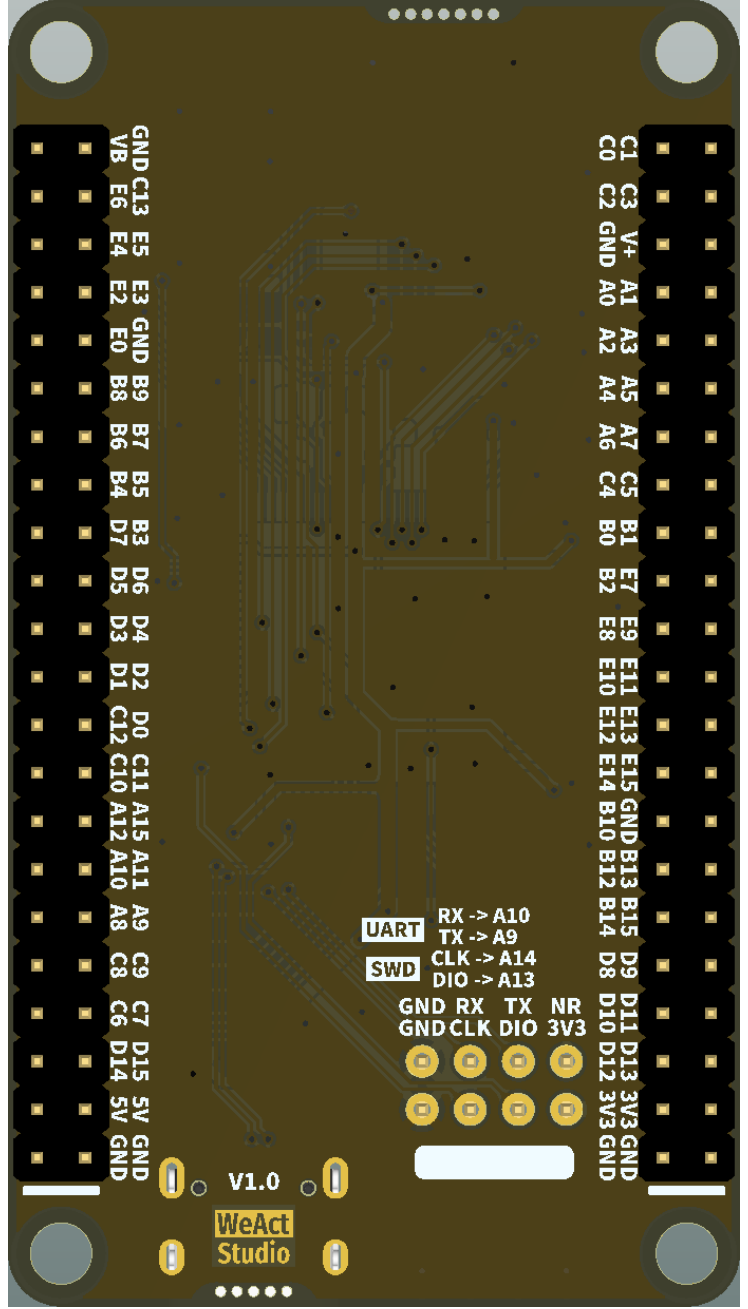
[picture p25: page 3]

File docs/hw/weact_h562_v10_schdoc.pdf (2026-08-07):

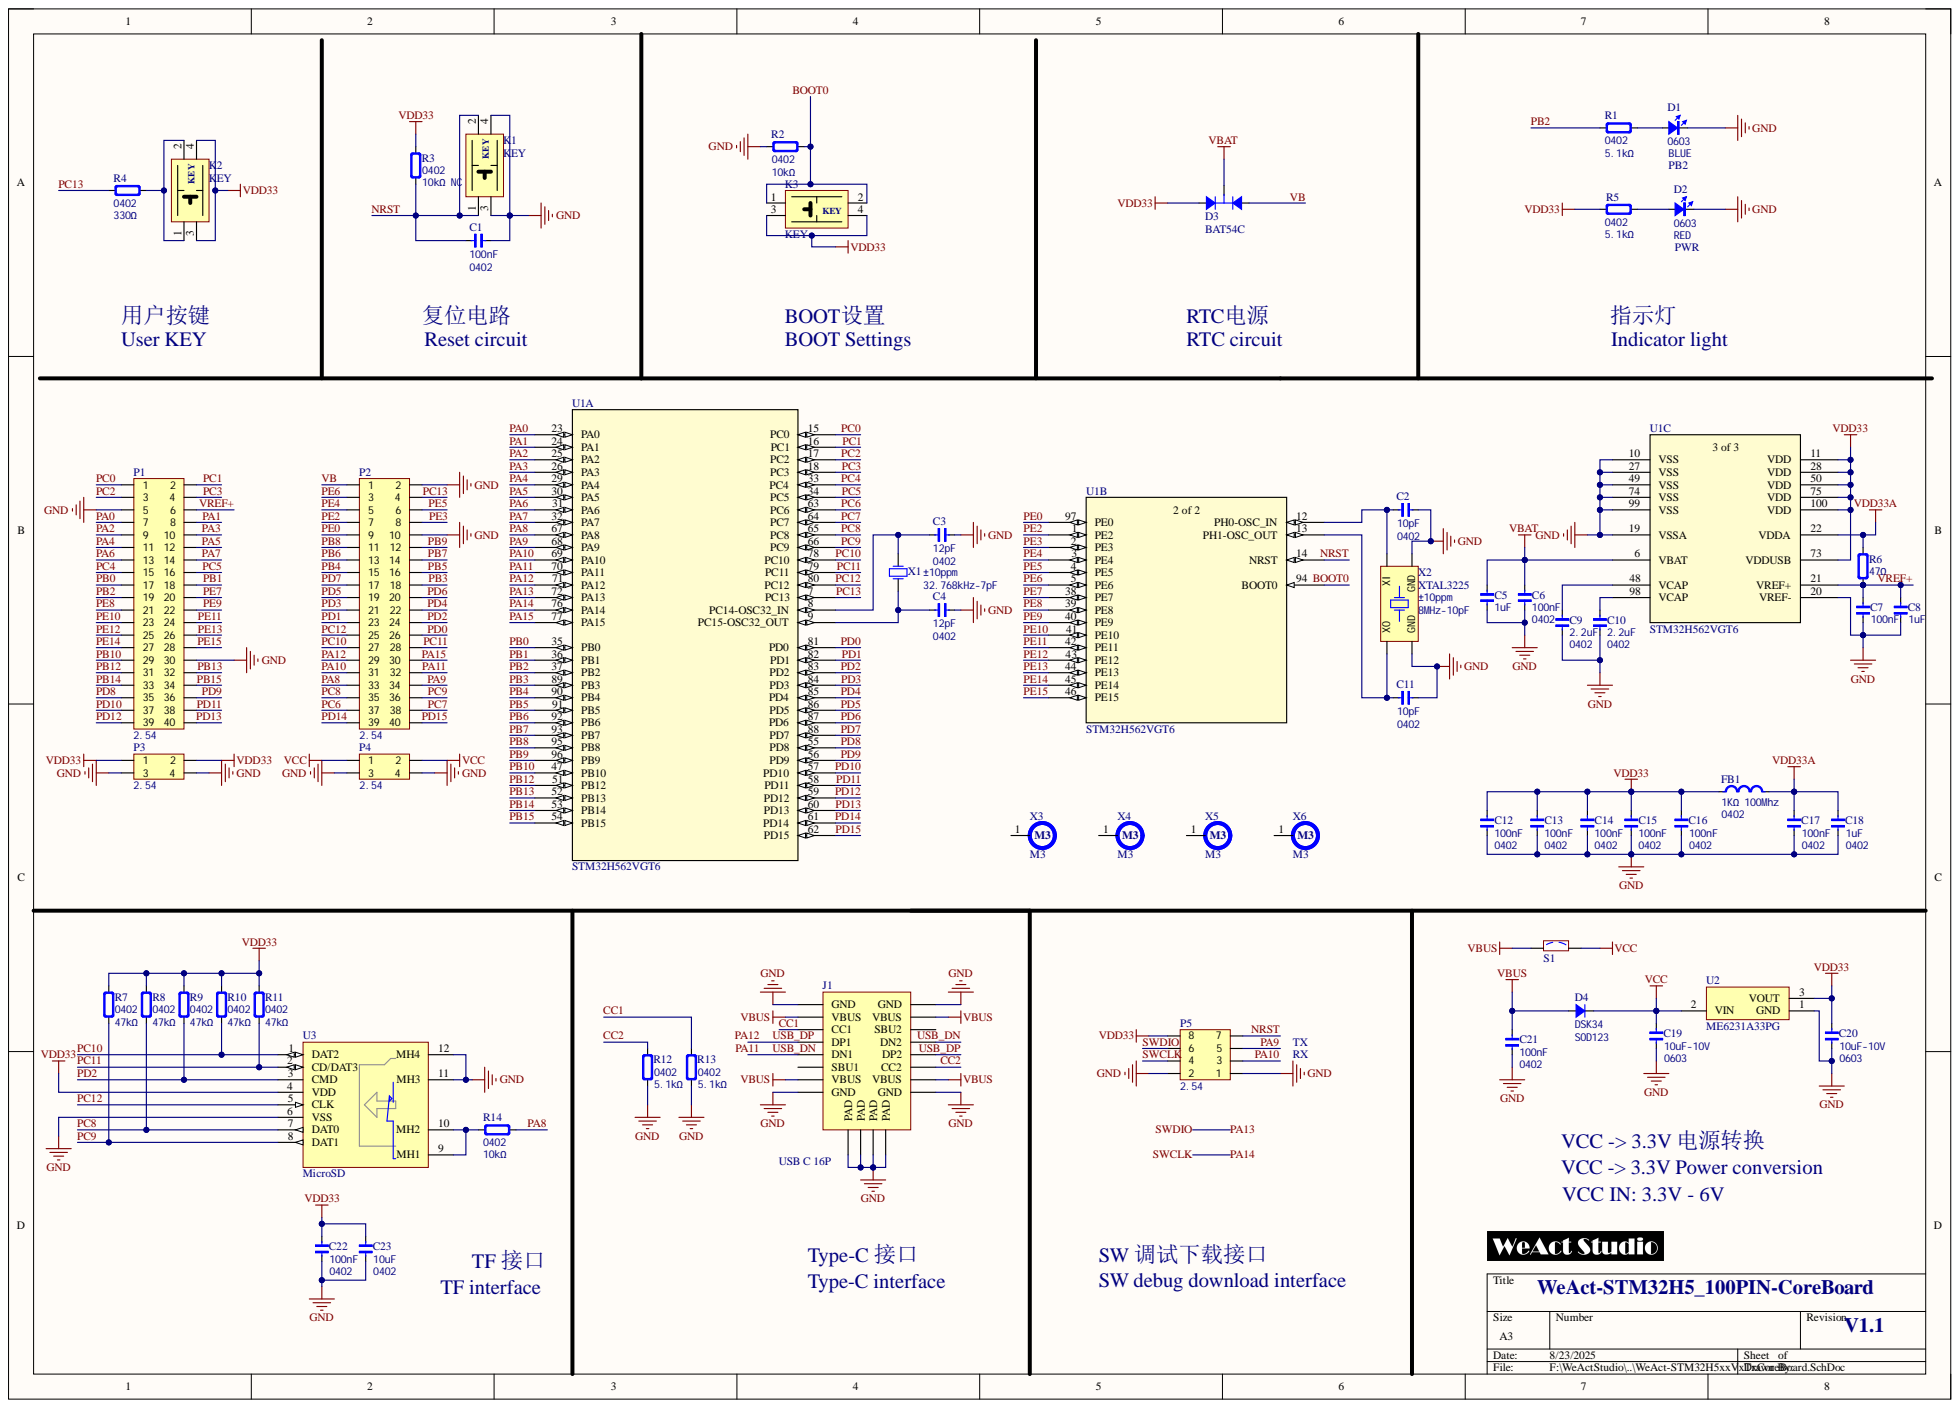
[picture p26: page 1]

VDD 4
CLK 5
VSS 6

PC8 | DAT0 7

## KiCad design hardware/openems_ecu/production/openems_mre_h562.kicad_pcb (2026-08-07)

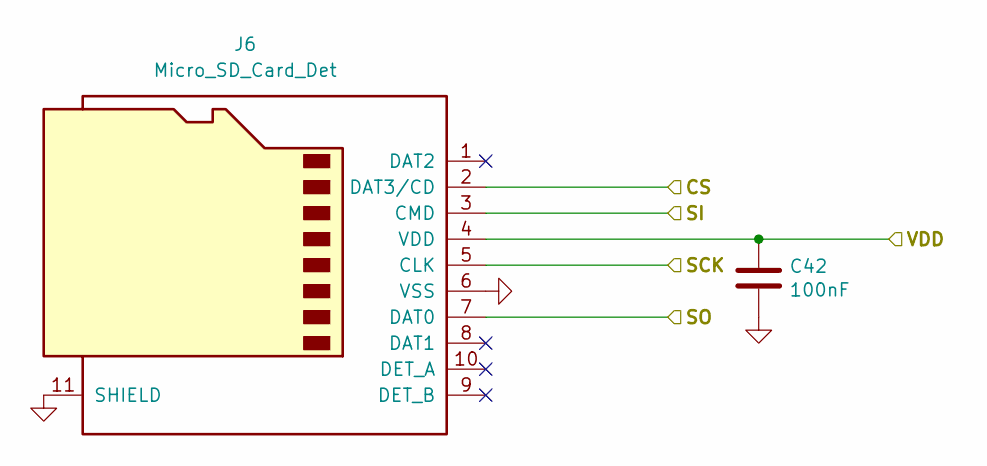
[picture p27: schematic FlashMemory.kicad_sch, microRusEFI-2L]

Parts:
C42: 100nF; C_0603_1608Metric; Part # C0603C104J5RACTU; LCSC C14663
J6: Micro_SD_Card_Det; microSD_HC_Molex_104031-0811; LCSC C585350

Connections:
/FlashMemory/CS: J6.2 (DAT3/CD); also elsewhere on the board
/FlashMemory/SCK: J6.5 (CLK); also elsewhere on the board
/FlashMemory/SI: J6.3 (CMD); also elsewhere on the board
/FlashMemory/SO: J6.7 (DAT0); also elsewhere on the board

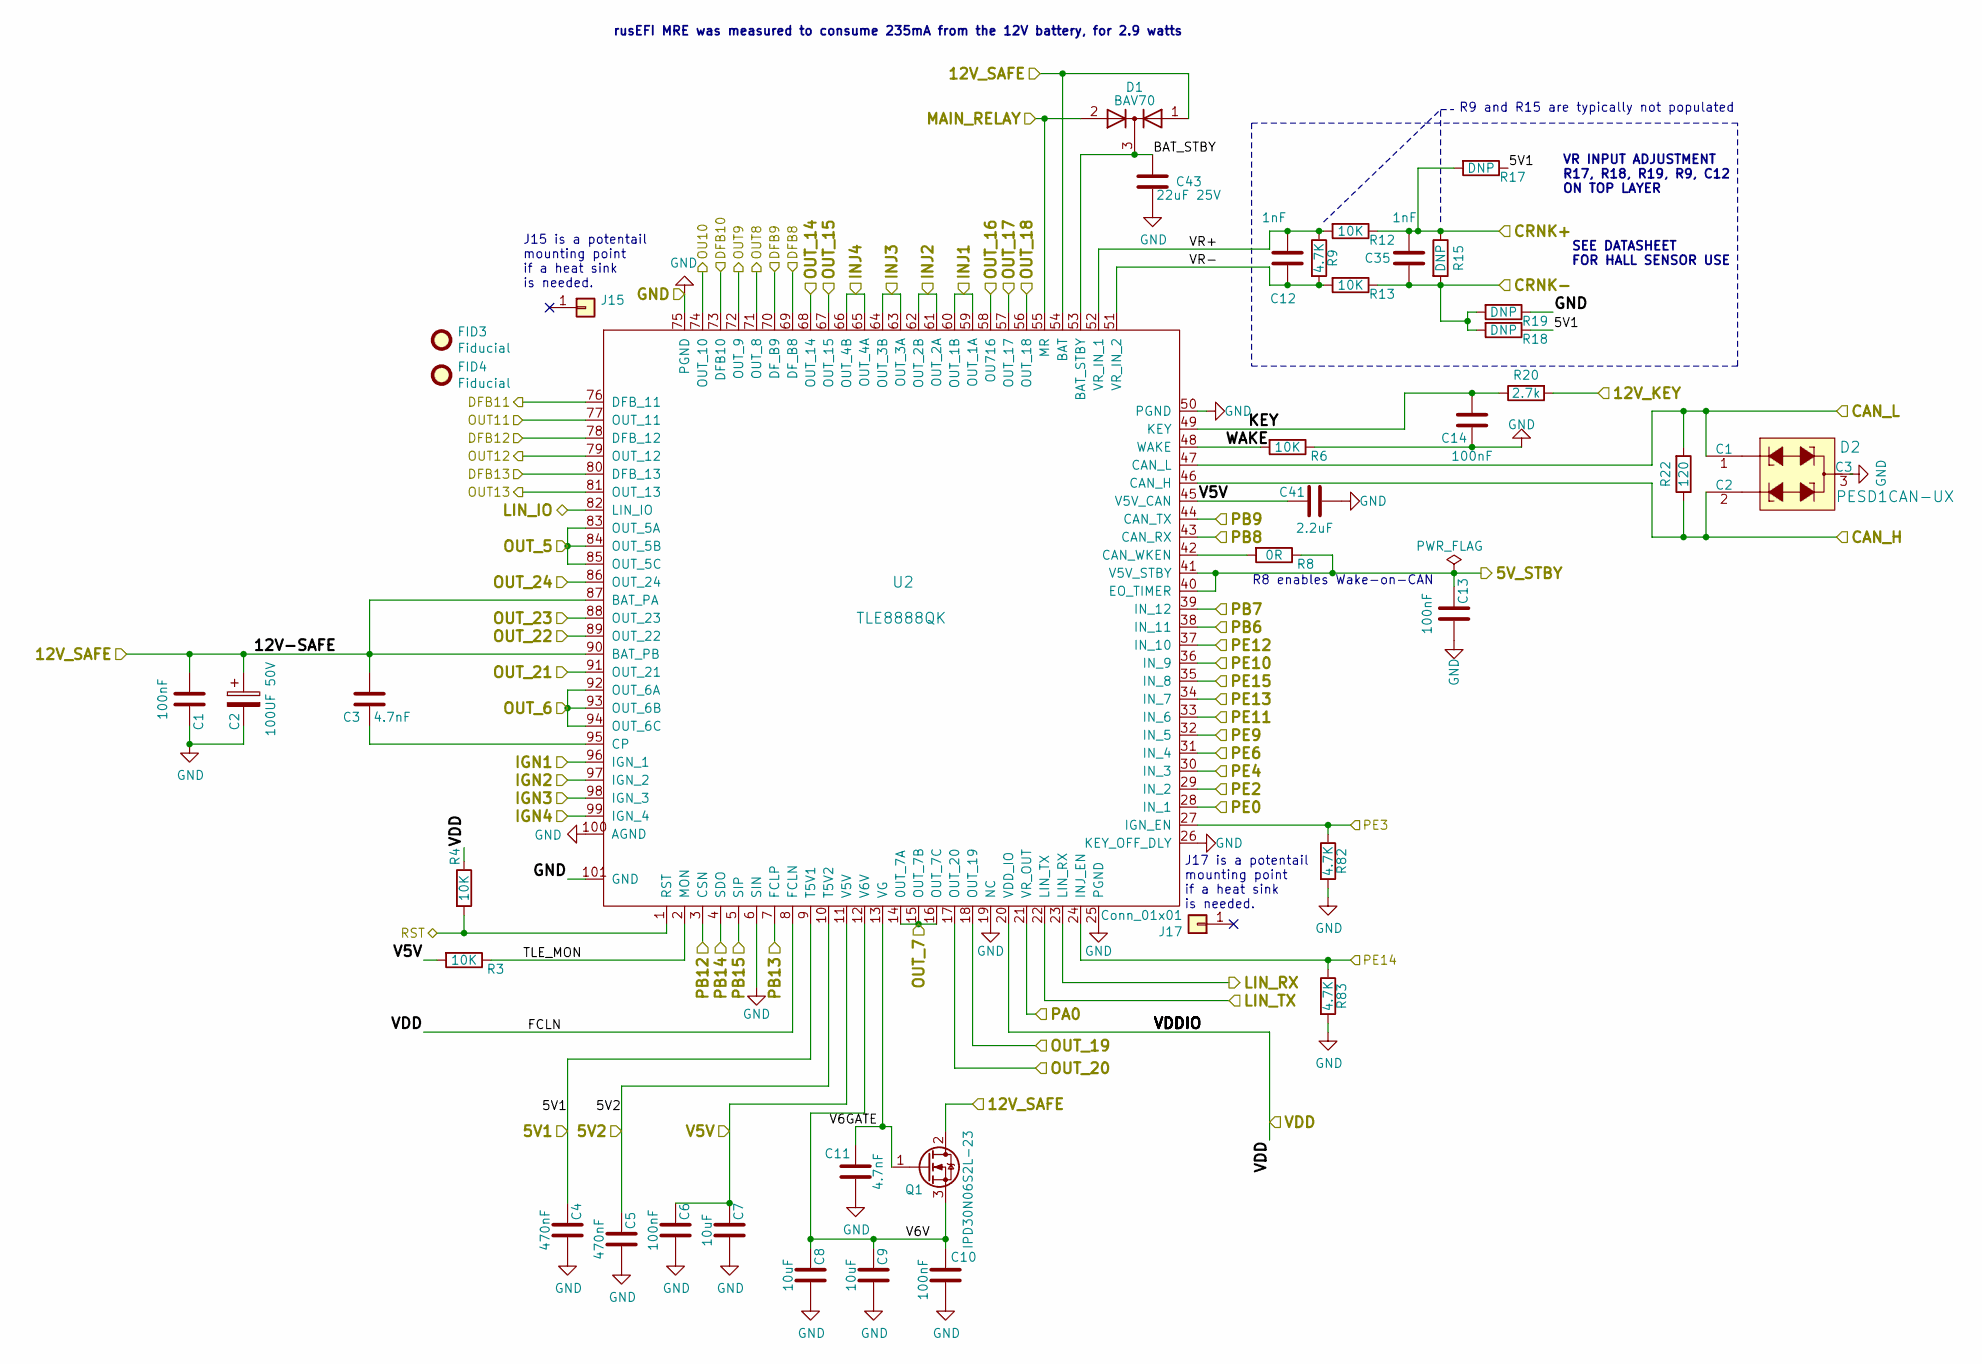
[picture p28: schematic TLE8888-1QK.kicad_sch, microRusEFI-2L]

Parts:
C1, C6, C10, C13, C14: 100nF; C_0603_1608Metric; Part # C0603C104J5RACTU; LCSC C14663
C2: 100UF 50V; CP_Elec_8x10.5; Part # UCD1H101MNL1GS; LCSC C134515
C3, C11: 4.7nF; C_0603_1608Metric; Part # CGA3E2X7R1H472K080AA; LCSC C53987
C4, C5: 470nF; C_0603_1608Metric; Part # CGA3E3X7R1H474K080AE; LCSC C1623
C7, C8, C9: 10uF; C_0603_1608Metric; Part # C1608X5R1E106M080AC; LCSC C19702
C12, C35: 1nF; C_0603_1608Metric; Part # GRM1885C1H102FA01D; LCSC C1588
C41: 2.2uF; C_0603_1608Metric; Part # GRM188R6YA225KA12D; LCSC C23630
C43: 22uF 25V; C_0805_2012Metric; Part # CL21A226MAQNNNE; LCSC C45783
D1: BAV70; SOT-23; LCSC C82479
D2: PESD1CAN-UX; SOT-23; Part # PESD1CANUX; LCSC C152727
FID3, FID4: Fiducial; Fiducial_0.5mm_Mask1mm; Part # DNP
J15, J17: Conn_01x01; Pin_D0.7mm_L6.5mm_W1.8mm_FlatFork
Q1: IPD30N06S2L-23; TO-252-2; Part # IPD30N06S2L23AT3; LCSC C3010
R3: 10K; R_0805_2012Metric; LCSC C17414
R4, R6, R12, R13: 10K; R_0603_1608Metric; Part # RMCF0603JT10K0; LCSC C25804
R8: 0R; R_0603_1608Metric; Part # 0603WAF0000T5E; LCSC C21189
R9: 4.7K; R_0603_1608Metric; Part # RMCF0603JT4K70; LCSC DNP
R15, R17, R18, R19: DNP; R_0603_1608Metric; Part # DNP
R20: 2.7k; R_0603_1608Metric; Part # RMCF0603FT2K70; LCSC C13167
R22: 120; R_0805_2012Metric; LCSC C17437
R82, R83: 4.7K; R_0603_1608Metric; Part # RMCF0603JT4K70; LCSC C23162
U2: TLE8888QK; LQFP-100_14x14mm_P0.5mm_THERMAL; Part # TLE88882QKXUMA1

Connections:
/5V: C6.1, C7.1, C41.1, R3.2, U2.11 (V5V), U2.45 (V5V_CAN); also elsewhere on the board
/5V1: C4.1, R17.1, R18.1, U2.9 (T5V1); also elsewhere on the board
/5V2: C5.1, U2.10 (T5V2); also elsewhere on the board
/12V_KEY: R20.2; also elsewhere on the board
/12V_SAFE: C1.1, C2.1, C3.1, D1.1 (A), Q1.2 (D), U2.54 (BAT), U2.87 (BAT_PA), U2.90 (BAT_PB); also elsewhere on the board
/AV6: U2.78 (DFB_12); also elsewhere on the board
/AV8: U2.76 (DFB_11); also elsewhere on the board
/AV9: U2.73 (DFB10); also elsewhere on the board
/AV10: U2.80 (DFB_13); also elsewhere on the board
/CANH: D2.2 (C2), R22.1, U2.46 (CAN_H); also elsewhere on the board
/CANL: D2.1 (C1), R22.2, U2.47 (CAN_L); also elsewhere on the board
/CRANK: U2.21 (VR_OUT); also elsewhere on the board
/CRNK+: C35.1, R12.1, R15.1, R17.2; also elsewhere on the board
/CRNK-: C35.2, R13.1, R15.2, R18.2, R19.2; also elsewhere on the board
/CS_TLE: U2.3 (CSN); also elsewhere on the board
/GP1: U2.91 (OUT_21); also elsewhere on the board
/GP2: U2.89 (OUT_22); also elsewhere on the board
/GP3: U2.88 (OUT_23); also elsewhere on the board
/GP4: U2.86 (OUT_24); also elsewhere on the board
/INJECTOR-1: U2.59 (OUT_1A), U2.60 (OUT_1B); also elsewhere on the board
/INJECTOR-2: U2.61 (OUT_2A), U2.62 (OUT_2B); also elsewhere on the board
/INJECTOR-3: U2.63 (OUT_3A), U2.64 (OUT_3B); also elsewhere on the board
/INJECTOR-4: U2.65 (OUT_4A), U2.66 (OUT_4B); also elsewhere on the board
/LINBUS: U2.82 (LIN_IO); also elsewhere on the board
/LS1: U2.92 (OUT_6A), U2.93 (OUT_6B), U2.94 (OUT_6C); also elsewhere on the board
/LS2: U2.83 (OUT_5A), U2.84 (OUT_5B), U2.85 (OUT_5C); also elsewhere on the board
/MAIN_RELAY: D1.2 (A), U2.55 (MR); also elsewhere on the board
/MCU/PB6: U2.44 (CAN_TX); also elsewhere on the board
/MCU/PB12: U2.43 (CAN_RX); also elsewhere on the board
/MCU/PD8: U2.22 (LIN_TX); also elsewhere on the board
/MCU/PD9: U2.23 (LIN_RX); also elsewhere on the board
/MCU/PD10: R82.1, U2.27 (IGN_EN); also elsewhere on the board
/MCU/PD11: R83.1, U2.24 (INJ_EN); also elsewhere on the board
/MCU/PE7: U2.39 (IN_12); also elsewhere on the board
/MCU/PE8: U2.38 (IN_11); also elsewhere on the board
/MCU/PE9: U2.37 (IN_10); also elsewhere on the board
/MCU/PE10: U2.36 (IN_9); also elsewhere on the board
/MCU/PE11: U2.31 (IN_4); also elsewhere on the board
/MCU/PE12: U2.30 (IN_3); also elsewhere on the board
/MCU/PE13: U2.29 (IN_2); also elsewhere on the board
/MCU/PE14: U2.28 (IN_1); also elsewhere on the board
/PD12: U2.32 (IN_5); also elsewhere on the board
/PD13: U2.33 (IN_6); also elsewhere on the board
/PD14: U2.34 (IN_7); also elsewhere on the board
/PD15: U2.35 (IN_8); also elsewhere on the board
/SCK: U2.7 (FCLP); also elsewhere on the board
/SI: U2.5 (SIP); also elsewhere on the board
/SO: U2.4 (SDO); also elsewhere on the board
/TLE8888-1QK/5V_STBY: C13.1, R8.1, U2.40 (EO_TIMER), U2.41 (V5V_STBY); also elsewhere on the board
/TLE8888-1QK/BAT_STBY: C43.1, D1.3 (K), U2.53 (BAT_STBY)
/TLE8888-1QK/DFB8: U2.69 (DF_B8)
/TLE8888-1QK/DFB9: U2.70 (DF_B9)
/TLE8888-1QK/IGN_OUT_1: U2.96 (IGN_1); also elsewhere on the board
/TLE8888-1QK/IGN_OUT_2: U2.97 (IGN_2); also elsewhere on the board
/TLE8888-1QK/IGN_OUT_3: U2.98 (IGN_3); also elsewhere on the board
/TLE8888-1QK/IGN_OUT_4: U2.99 (IGN_4); also elsewhere on the board
/TLE8888-1QK/KEY: C14.1, R20.1, U2.49 (KEY)
/TLE8888-1QK/OUT8: U2.71 (OUT_8)
/TLE8888-1QK/OUT9: U2.72 (OUT_9)
/TLE8888-1QK/OUT_7: U2.14 (0UT_7A), U2.15 (OUT_7B), U2.16 (OUT_7C); also elsewhere on the board
/TLE8888-1QK/OUT_14: U2.68 (OUT_14); also elsewhere on the board
/TLE8888-1QK/OUT_15: U2.67 (OUT_15); also elsewhere on the board
/TLE8888-1QK/OUT_16: U2.58 (OU716); also elsewhere on the board
/TLE8888-1QK/OUT_17: U2.57 (OUT_17); also elsewhere on the board
/TLE8888-1QK/OUT_18: U2.56 (OUT_18); also elsewhere on the board
/TLE8888-1QK/OUT_19: U2.18 (OUT_19)
/TLE8888-1QK/OUT_20: U2.17 (OUT_20)
/TLE8888-1QK/RST: R4.2, U2.1 (RST); also elsewhere on the board
/TLE8888-1QK/TLE_MON: R3.1, U2.2 (MON)
/TLE8888-1QK/V6GATE: C11.1, Q1.1 (G), U2.13 (VG)
/TLE8888-1QK/V6V: C8.1, C9.1, C10.1, Q1.3 (S), U2.12 (V6V)
/TLE8888-1QK/VR+: C12.1, R9.1, R12.2, U2.52 (VR_IN_1)
/TLE8888-1QK/VR-: C12.2, R9.2, R13.2, U2.51 (VR_IN_2)
/TLE8888-1QK/WAKE: R6.2, U2.48 (WAKE)
/TLE_OUT10_PRE: U2.74 (OUT_10); also elsewhere on the board
/TLE_OUT11_PRE: U2.77 (OUT_11); also elsewhere on the board
/TLE_OUT12_PRE: U2.79 (OUT_12); also elsewhere on the board
/TLE_OUT13_PRE: U2.81 (OUT_13); also elsewhere on the board
unnamed: C3.2, U2.95 (CP)
unnamed: R8.2, U2.42 (CAN_WKEN)

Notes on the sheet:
J15 is a potentail mounting point if a heat sink is needed.
rusEFI MRE was measured to consume 235mA from the 12V battery, for 2.9 watts
J17 is a potentail mounting point if a heat sink is needed.
R8 enables Wake-on-CAN
R9 and R15 are typically not populated
VR INPUT ADJUSTMENT R17, R18, R19, R9, C12 ON TOP LAYER
SEE DATASHEET FOR HALL SENSOR USE

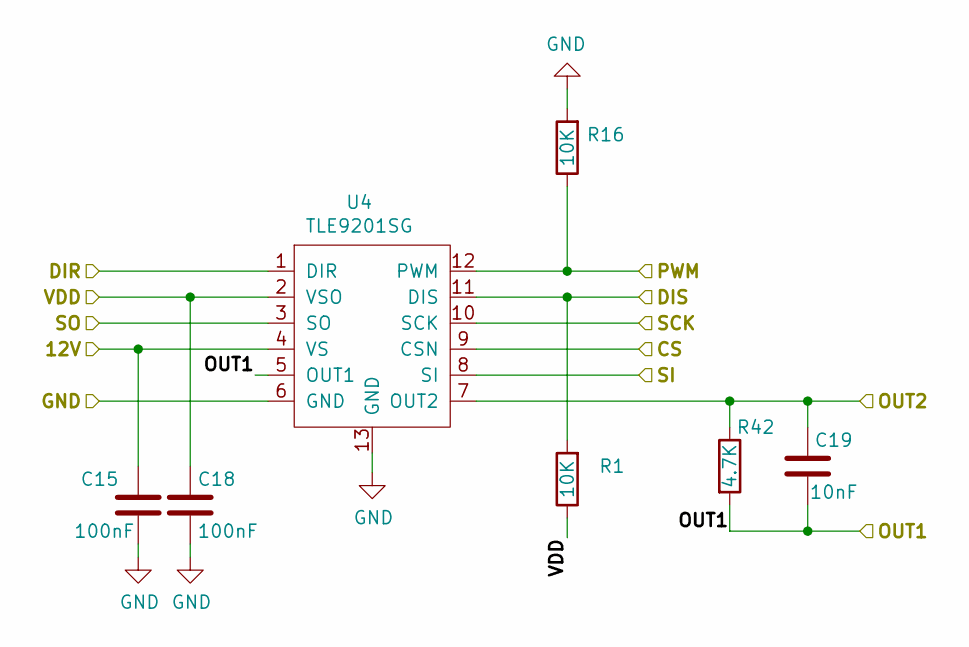
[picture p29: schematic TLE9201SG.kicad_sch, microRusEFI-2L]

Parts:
C15, C18: 100nF; C_0603_1608Metric; Part # C0603C104J5RACTU; LCSC C14663
C19: 10nF; C_0603_1608Metric; Part # C0603C103K1RACTU; LCSC C57112
R1, R16: 10K; R_0603_1608Metric; Part # RMCF0603JT10K0; LCSC C25804
R42: 4.7K; R_0603_1608Metric; Part # RMCF0603JT4K70; LCSC C23162
U4: TLE9201SG; Infineon_PG-DSO-12-11; Part # TLE9201SG; LCSC C112633

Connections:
/12V_MREL: C15.1, U4.4 (VS); also elsewhere on the board
/E-THROTTLE+: C19.2, R42.2, U4.5 (OUT1); also elsewhere on the board
/E-THROTTLE-: C19.1, R42.1, U4.7 (OUT2); also elsewhere on the board
/H-BRIDGE/DIR: U4.1 (DIR); also elsewhere on the board
/H-BRIDGE/DIS: R1.2, U4.11 (DIS); also elsewhere on the board
/H-BRIDGE/PWM: R16.1, U4.12 (PWM); also elsewhere on the board
/H-BRIDGE/SO: U4.3 (SO); also elsewhere on the board

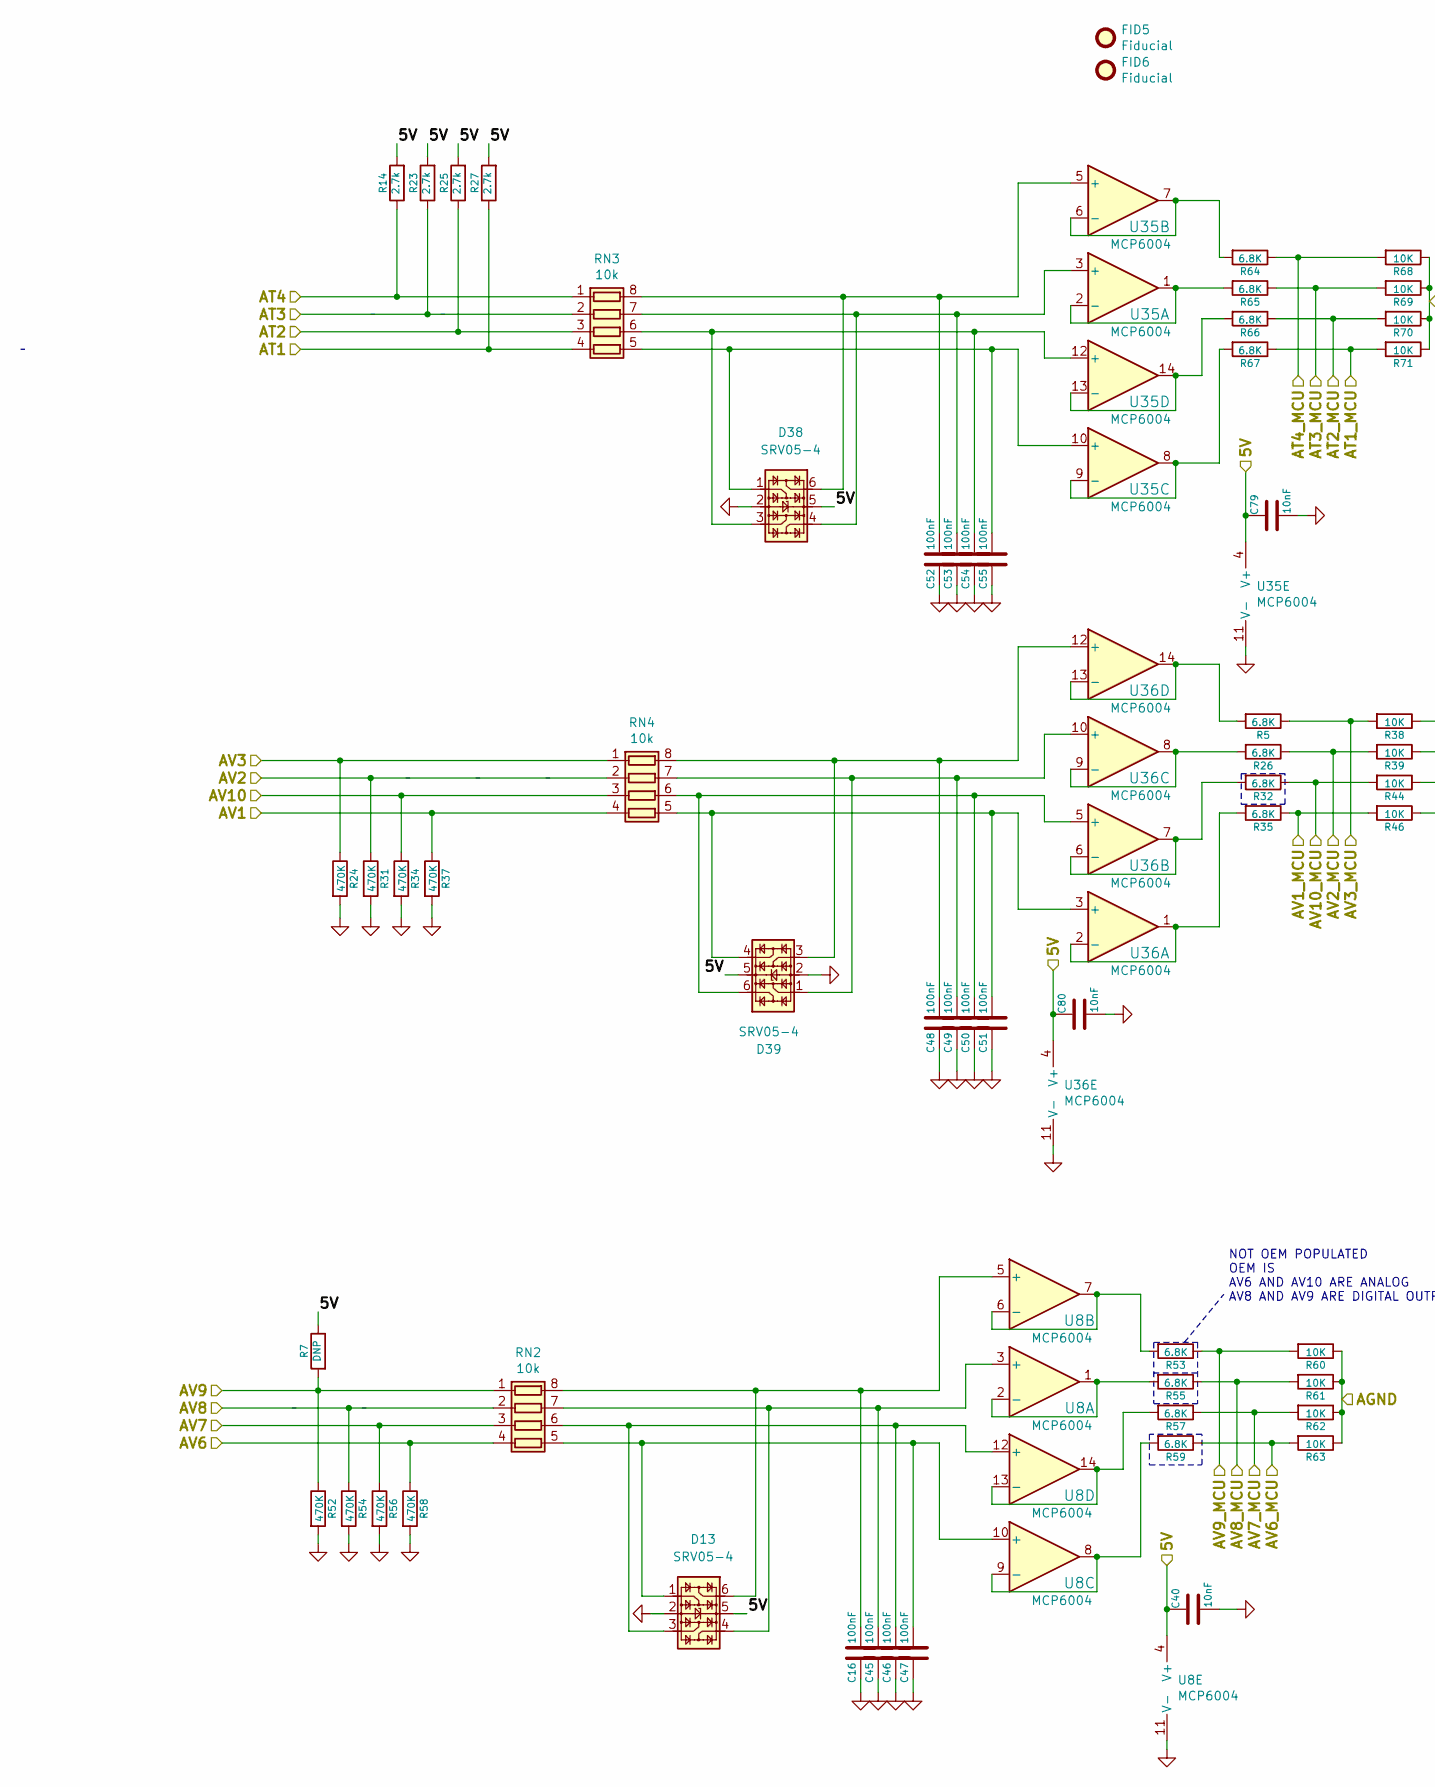
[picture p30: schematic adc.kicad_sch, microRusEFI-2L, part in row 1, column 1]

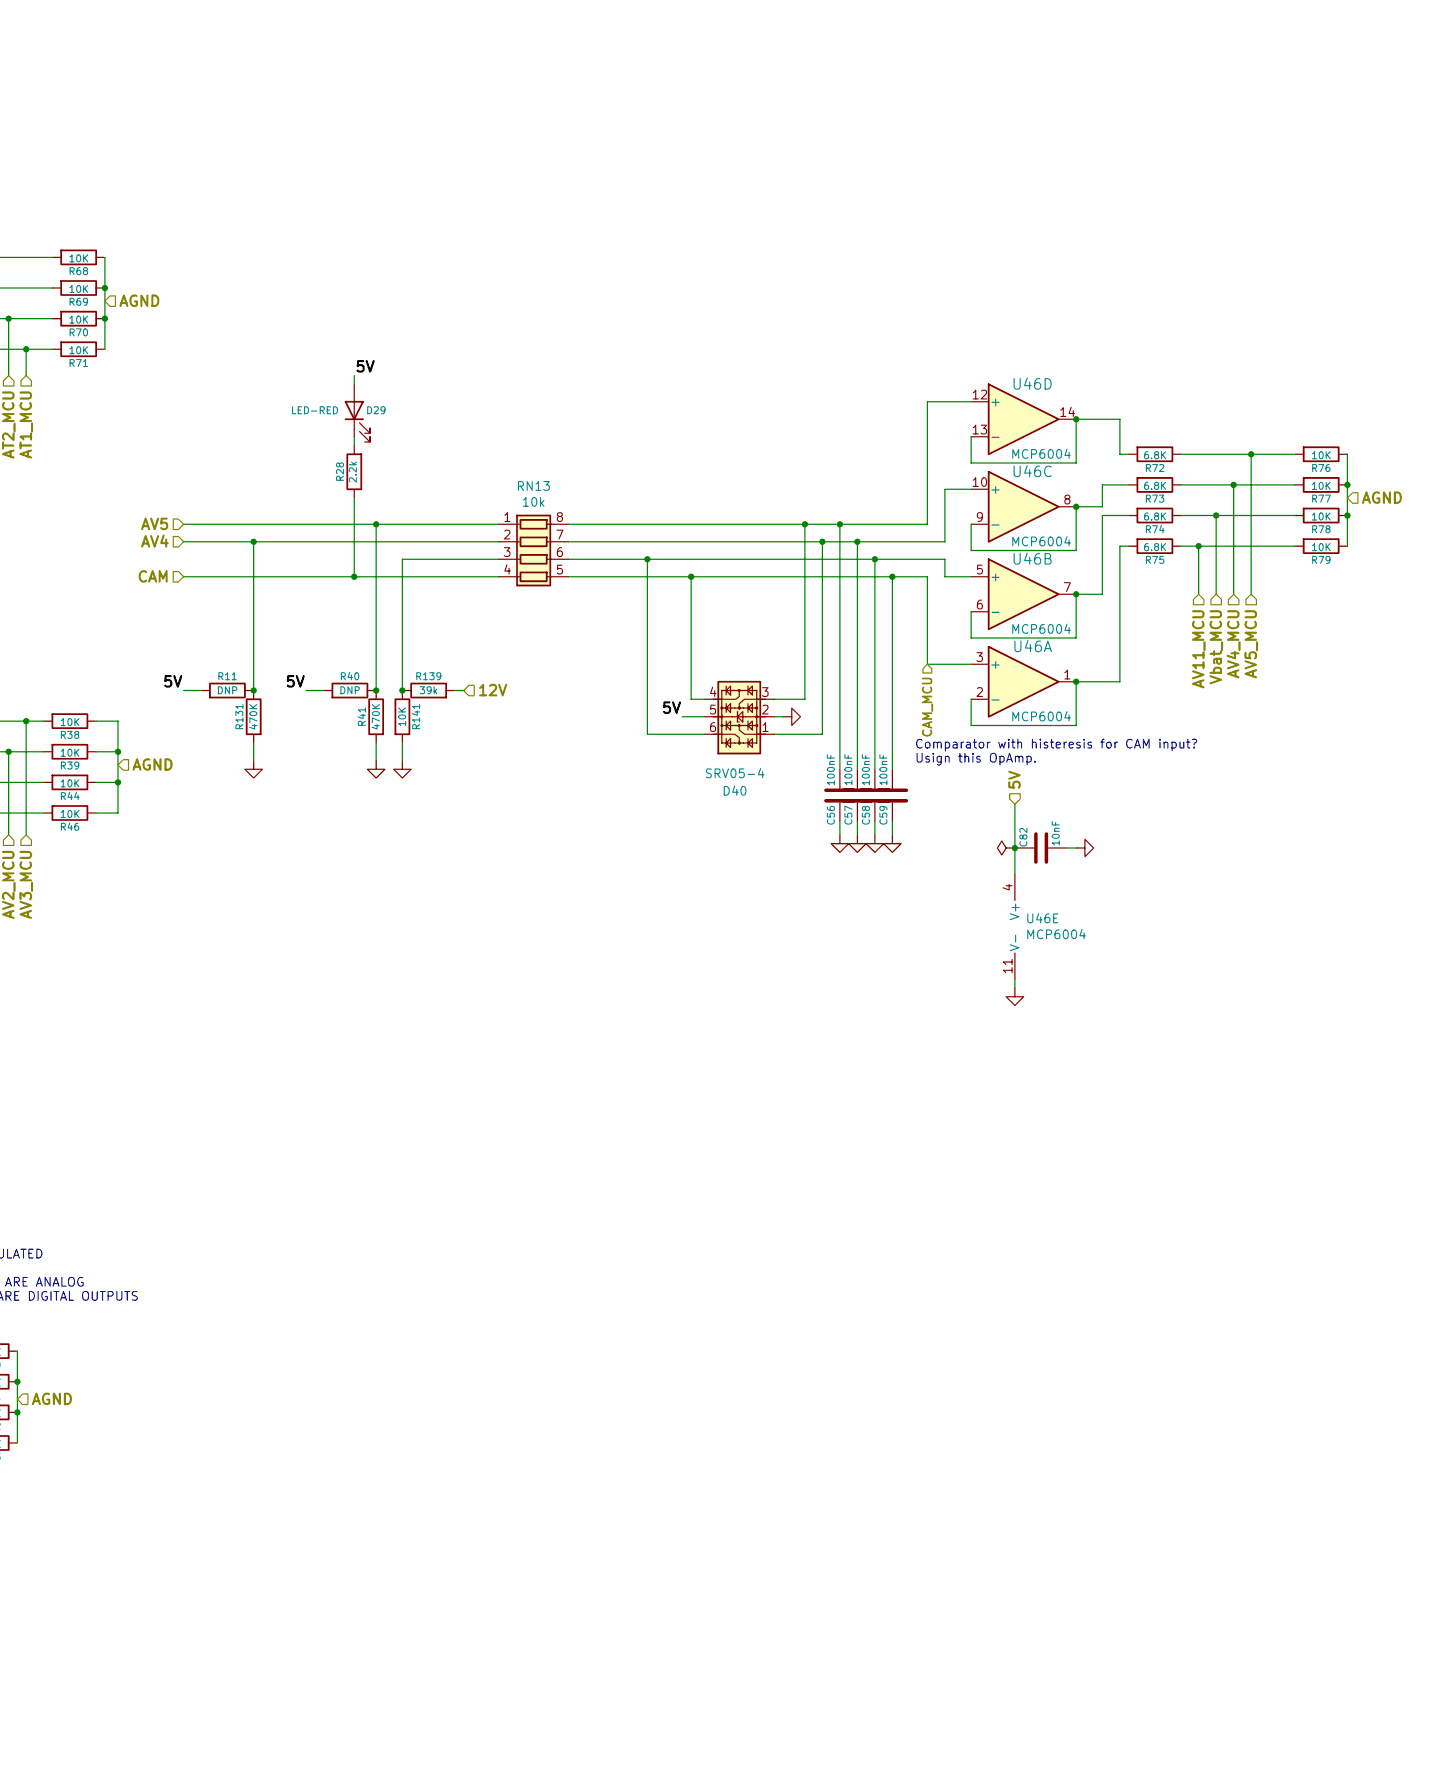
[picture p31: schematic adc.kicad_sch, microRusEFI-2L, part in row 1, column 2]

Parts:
C16, C45, C46, C47, C48, C49, C50, C51, C52, C53, C54, C55, C56, C57, C58, C59: 100nF; C_0402_1005Metric; LCSC C1525
C40, C79, C80, C82: 10nF; C_0603_1608Metric; Part # C0603C103K1RACTU; LCSC C57112
D13, D38, D39, D40: SRV05-4; SOT-23-6; LCSC C85364
D29: LED-RED; LED_0603_1608Metric; LCSC C2286
FID5, FID6: Fiducial; Fiducial_0.5mm_Mask1mm; Part # DNP
R5, R26, R32, R35, R57, R59, R64, R65, R66, R67, R72, R73, R74, R75: 6.8K; R_0603_1608Metric; LCSC C23212
R7, R11, R40: DNP; R_0402_1005Metric; Part # DNP
R14, R23, R25, R27: 2.7k; R_0603_1608Metric; Part # RMCF0603FT2K70; LCSC C13167
R24, R31, R34, R37, R41, R52, R54, R56, R58, R131: 470K; R_0402_1005Metric; LCSC C25790
R28: 2.2k; R_0603_1608Metric; Part # RMCF0603FT2K20; LCSC C4190
R38, R39, R44, R46, R60, R61, R62, R63, R68, R69, R70, R71, R76, R77, R78, R79, R141: 10K; R_0603_1608Metric; Part # RMCF0603JT10K0; LCSC C25804
R53, R55: 6.8K; R_0603_1608Metric
R139: 39k; R_0603_1608Metric; Part # RC0603FR-0739KL; LCSC C23153
RN2, RN3, RN4, RN13: 10k; R_Array_Convex_4x0603; Part # YC164-JR-0710KL; LCSC C29718
U8, U35, U36, U46: MCP6004; TSSOP-14_4.4x5mm_P0.65mm; Part # MCP6004T-I/ST; LCSC C248577

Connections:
/5V: C40.1, C79.1, C80.1, C82.1, D13.5, D29.2 (A), D38.5, D39.5, D40.5, R7.1, R11.2, R14.2, R23.2, R25.2, R27.2, R40.2, U8.4 (V+), U35.4 (V+), U36.4 (V+), U46.4 (V+); also elsewhere on the board
/12V_MREL: R139.2; also elsewhere on the board
/ADC/AV11_MCU: R75.1, R79.2; also elsewhere on the board
/AT1: R27.1, RN3.4 (R4.1); also elsewhere on the board
/AT1_MCU: R67.1, R71.2; also elsewhere on the board
/AT2: R25.1, RN3.3 (R3.1); also elsewhere on the board
/AT2_MCU: R66.1, R70.2; also elsewhere on the board
/AT3: R23.1, RN3.2 (R2.1); also elsewhere on the board
/AT3_MCU: R65.1, R69.2; also elsewhere on the board
/AT4: R14.1, RN3.1 (R1.1); also elsewhere on the board
/AT4_MCU: R64.1, R68.2; also elsewhere on the board
/AV1: R37.1, RN4.4 (R4.1); also elsewhere on the board
/AV1_MCU: R35.1, R46.2; also elsewhere on the board
/AV2: R31.1, RN4.2 (R2.1); also elsewhere on the board
/AV2_MCU: R26.1, R39.2; also elsewhere on the board
/AV3: R24.1, RN4.1 (R1.1); also elsewhere on the board
/AV3_MCU: R5.1, R38.2; also elsewhere on the board
/AV4: R11.1, R131.1, RN13.2 (R2.1); also elsewhere on the board
/AV4_MCU: R73.1, R77.2; also elsewhere on the board
/AV5: R40.1, R41.1, RN13.1 (R1.1); also elsewhere on the board
/AV5_MCU: R72.1, R76.2; also elsewhere on the board
/AV6: R58.1, RN2.4 (R4.1); also elsewhere on the board
/AV6_MCU: R59.1, R63.2; also elsewhere on the board
/AV7: R56.1, RN2.3 (R3.1); also elsewhere on the board
/AV7_MCU: R57.1, R62.2; also elsewhere on the board
/AV8: R54.1, RN2.2 (R2.1); also elsewhere on the board
/AV8_MCU: R55.1, R61.2; also elsewhere on the board
/AV9: R7.2, R52.1, RN2.1 (R1.1); also elsewhere on the board
/AV9_MCU: R53.1, R60.2; also elsewhere on the board
/AV10: R34.1, RN4.3 (R3.1); also elsewhere on the board
/AV10_MCU: R32.1, R44.2; also elsewhere on the board
/CAM_MCU: C59.1, D40.4, RN13.5 (R4.2), U46.3 (+); also elsewhere on the board
/CAM_SENSOR: R28.1, RN13.4 (R4.1); also elsewhere on the board
/Vbat_MCU: R74.1, R78.2; also elsewhere on the board
unnamed: C16.1, D13.6, RN2.8 (R1.2), U8.5 (+)
unnamed: C45.1, D13.4, RN2.7 (R2.2), U8.3 (+)
unnamed: C46.1, D13.3, RN2.6 (R3.2), U8.12 (+)
unnamed: C47.1, D13.1, RN2.5 (R4.2), U8.10 (+)
unnamed: C48.1, D39.3, RN4.8 (R1.2), U36.12 (+)
unnamed: C49.1, D39.1, RN4.7 (R2.2), U36.10 (+)
unnamed: C50.1, D39.6, RN4.6 (R3.2), U36.5 (+)
unnamed: C51.1, D39.4, RN4.5 (R4.2), U36.3 (+)
unnamed: C52.1, D38.6, RN3.8 (R1.2), U35.5 (+)
unnamed: C53.1, D38.4, RN3.7 (R2.2), U35.3 (+)
unnamed: C54.1, D38.3, RN3.6 (R3.2), U35.12 (+)
unnamed: C55.1, D38.1, RN3.5 (R4.2), U35.10 (+)
unnamed: C56.1, D40.3, RN13.8 (R1.2), U46.12 (+)
unnamed: C57.1, D40.1, RN13.7 (R2.2), U46.10 (+)
unnamed: C58.1, D40.6, RN13.6 (R3.2), U46.5 (+)
unnamed: D29.1 (K), R28.2
unnamed: R5.2, U36.13 (-), U36.14
unnamed: R26.2, U36.8, U36.9 (-)
unnamed: R32.2, U36.6 (-), U36.7
unnamed: R35.2, U36.1, U36.2 (-)
unnamed: R53.2, U8.6 (-), U8.7
unnamed: R55.2, U8.1, U8.2 (-)
unnamed: R57.2, U8.13 (-), U8.14
unnamed: R59.2, U8.8, U8.9 (-)
unnamed: R64.2, U35.6 (-), U35.7
unnamed: R65.2, U35.1, U35.2 (-)
unnamed: R66.2, U35.13 (-), U35.14
unnamed: R67.2, U35.8, U35.9 (-)
unnamed: R72.2, U46.13 (-), U46.14
unnamed: R73.2, U46.8, U46.9 (-)
unnamed: R74.2, U46.6 (-), U46.7
unnamed: R75.2, U46.1, U46.2 (-)
unnamed: R139.1, R141.1, RN13.3 (R3.1)

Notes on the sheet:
Comparator with histeresis for CAM input? Usign this OpAmp.
NOT OEM POPULATED OEM IS AV6 AND AV10 ARE ANALOG AV8 AND AV9 ARE DIGITAL OUTPUTS

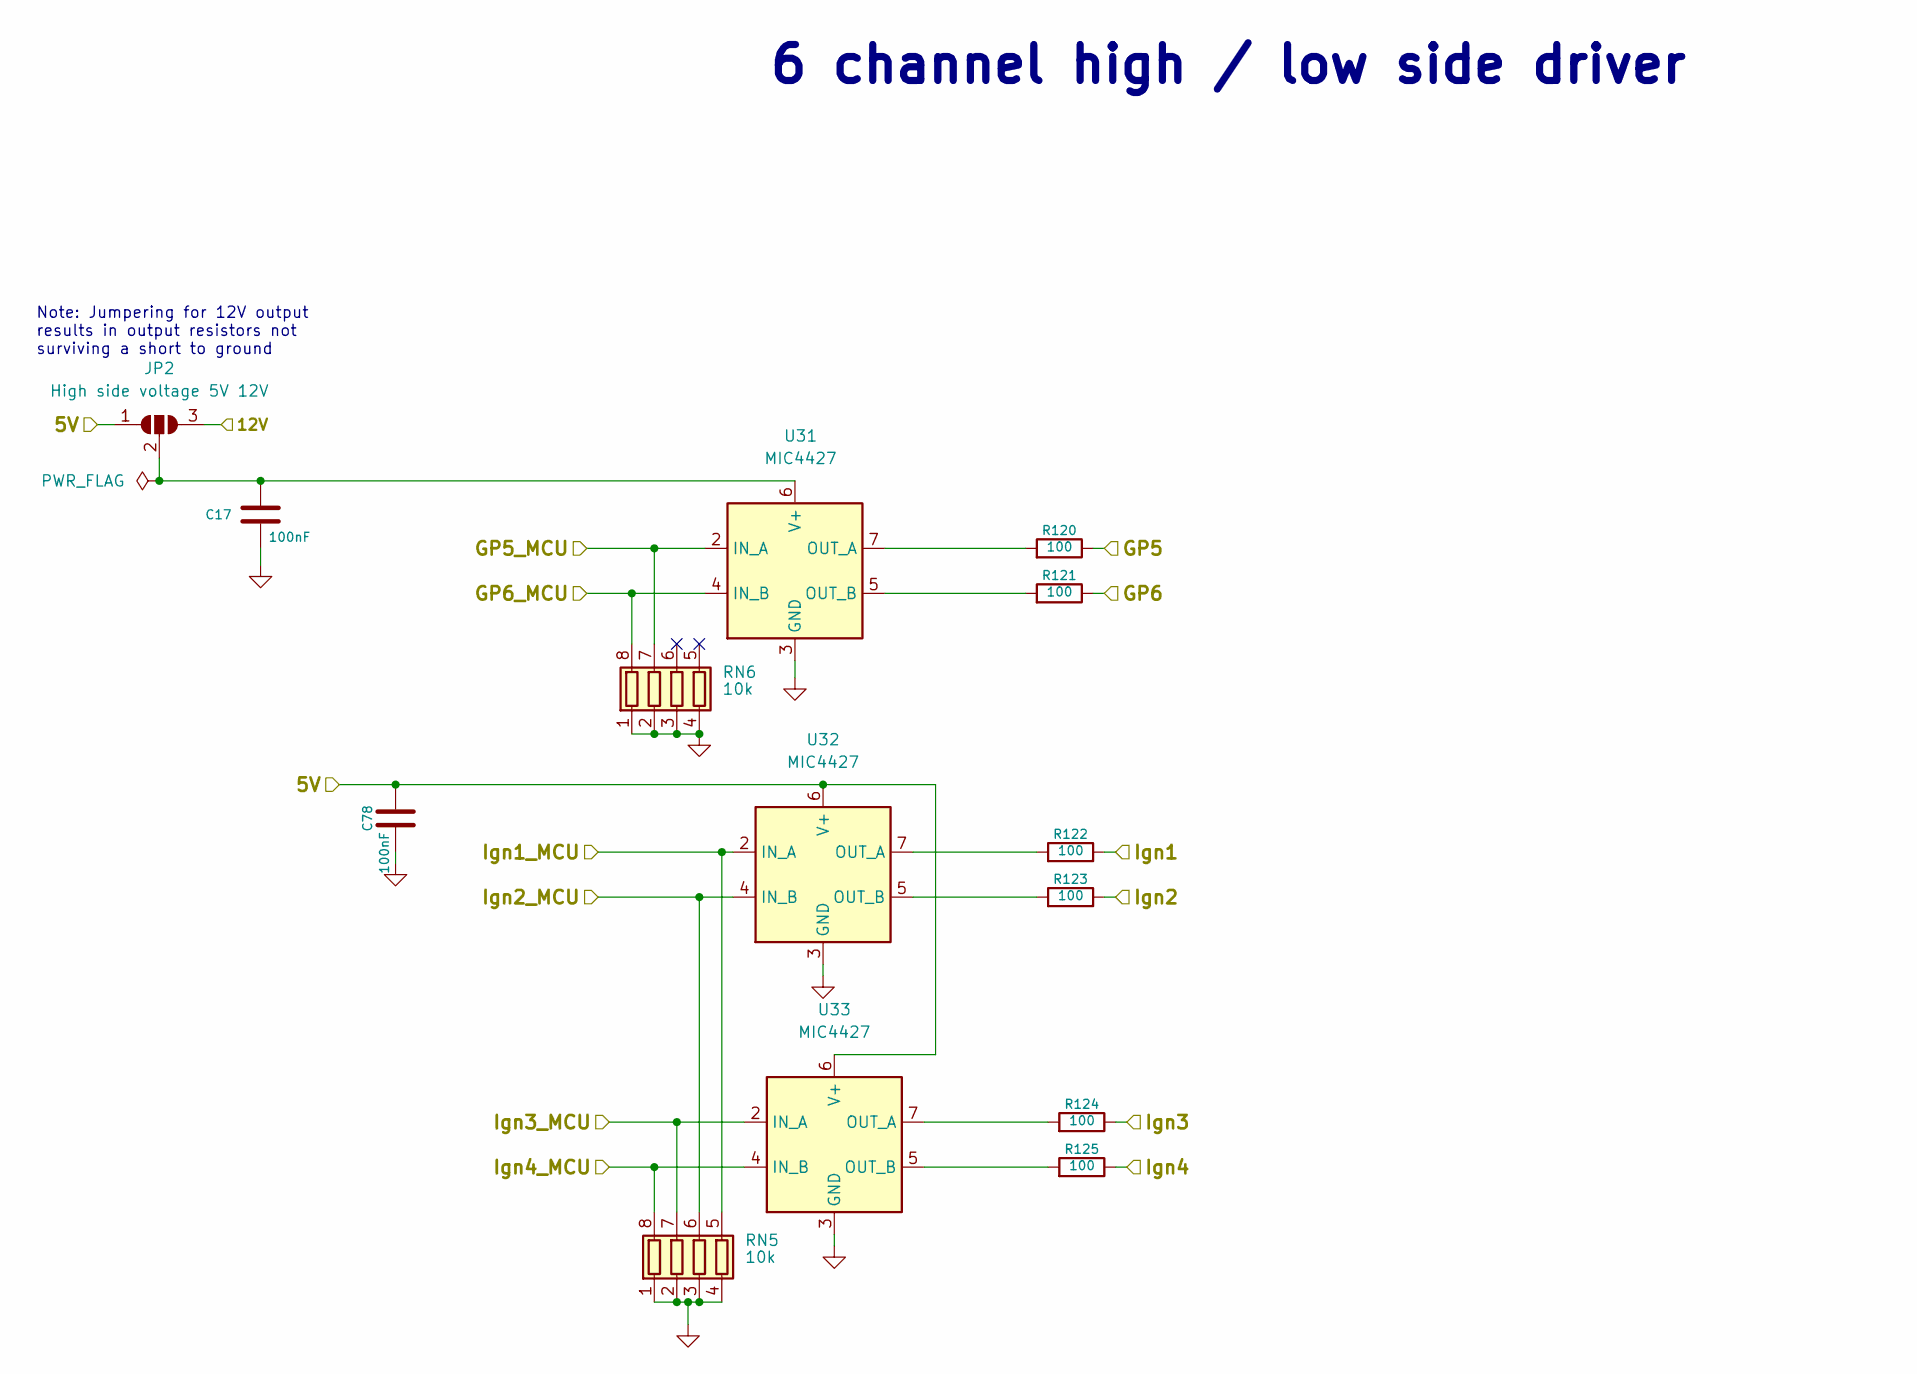
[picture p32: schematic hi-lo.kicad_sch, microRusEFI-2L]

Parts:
C17, C78: 100nF; C_0603_1608Metric; Part # C0603C104J5RACTU; LCSC C14663
JP2: High side voltage 5V 12V; SolderJumper-3_P1.3mm_Open_Pad1.0x1.5mm
R120, R121, R122, R123, R124, R125: 100; R_1206_3216Metric; Part # RMCF0603FT100R; LCSC C17901
RN5, RN6: 10k; R_Array_Convex_4x0603; Part # YC164-JR-0710KL; LCSC C29718
U31, U32, U33: MIC4427; SOIC-8_3.9x4.9mm_P1.27mm; LCSC C144205

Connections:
/5V: C78.1, JP2.1 (A), U32.6 (V+), U33.6 (V+); also elsewhere on the board
/12V_MREL: JP2.3 (B); also elsewhere on the board
/GP5: R120.1; also elsewhere on the board
/GP6: R121.1; also elsewhere on the board
/Ign1: R122.1; also elsewhere on the board
/Ign2: R123.1; also elsewhere on the board
/Ign3: R124.1; also elsewhere on the board
/Ign4: R125.1; also elsewhere on the board
/MCU/PD1: RN5.8 (R1.2), U33.4 (IN_B); also elsewhere on the board
/MCU/PD2: RN5.7 (R2.2), U33.2 (IN_A); also elsewhere on the board
/MCU/PD3: RN5.6 (R3.2), U32.4 (IN_B); also elsewhere on the board
/MCU/PD4: RN5.5 (R4.2), U32.2 (IN_A); also elsewhere on the board
/MCU/PD6: RN6.8 (R1.2), U31.4 (IN_B); also elsewhere on the board
/MCU/PD7: RN6.7 (R2.2), U31.2 (IN_A); also elsewhere on the board
unnamed: C17.1, JP2.2 (C), U31.6 (V+)
unnamed: R120.2, U31.7 (OUT_A)
unnamed: R121.2, U31.5 (OUT_B)
unnamed: R122.2, U32.7 (OUT_A)
unnamed: R123.2, U32.5 (OUT_B)
unnamed: R124.2, U33.7 (OUT_A)
unnamed: R125.2, U33.5 (OUT_B)

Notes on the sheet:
Note: Jumpering for 12V output results in output resistors not surviving a short to ground
6 channel high / low side driver

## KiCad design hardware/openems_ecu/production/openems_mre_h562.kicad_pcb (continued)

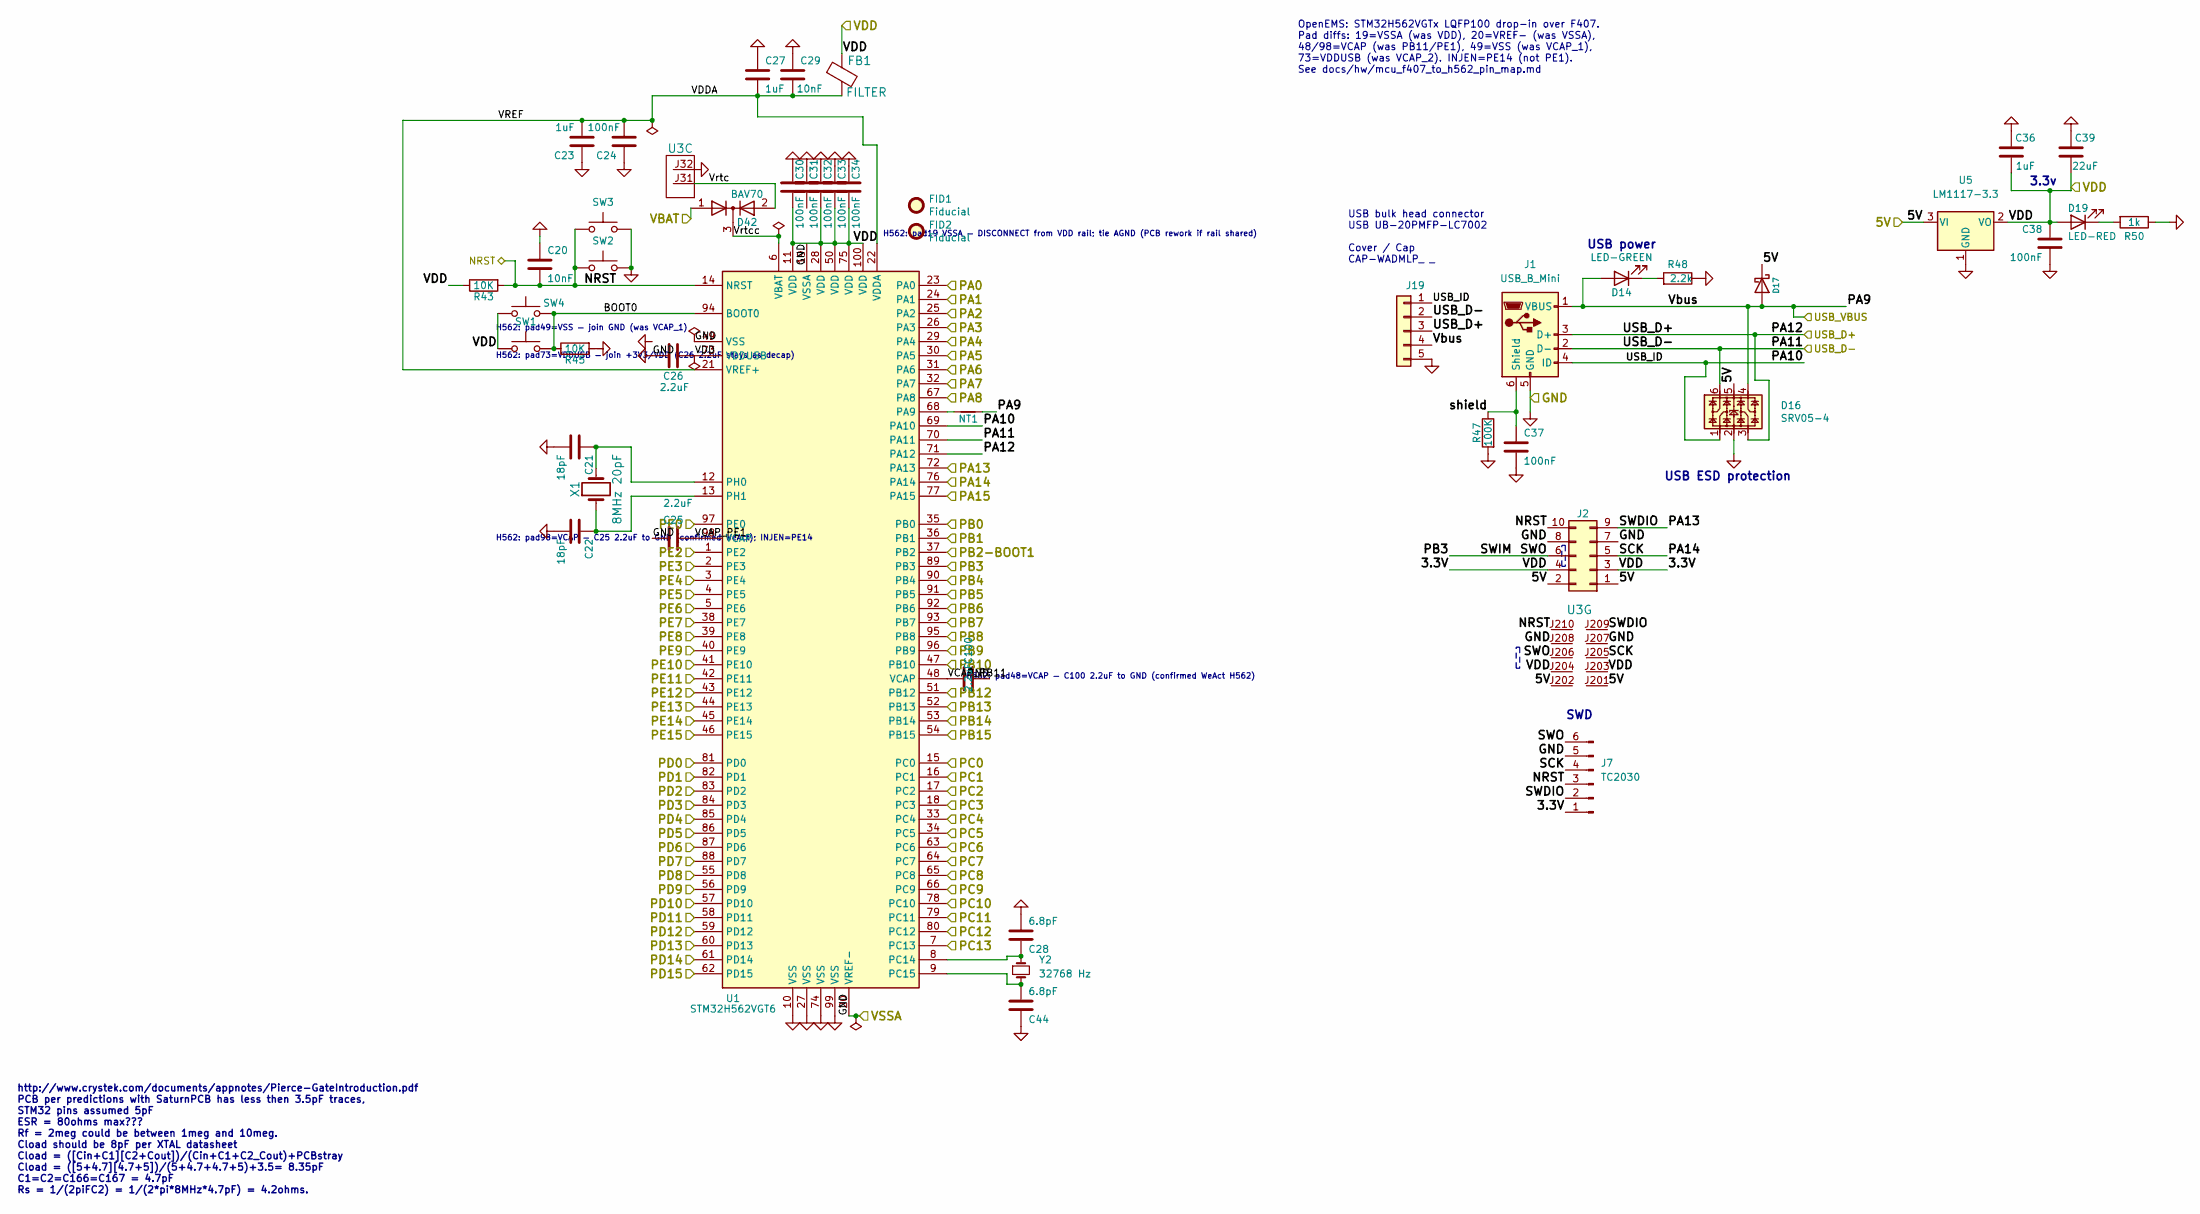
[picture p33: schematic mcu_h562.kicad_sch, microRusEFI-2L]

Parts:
C20, C29: 10nF; C_0603_1608Metric; Part # C0603C103K1RACTU; LCSC C57112
C21, C22: 18pF; C_0603_1608Metric; Part # CL10C180JB8NNNC; LCSC C1647
C23, C27, C36: 1uF; C_0603_1608Metric; Part # UMK107BJ105KA-T; LCSC C15849
C24, C30, C31, C32, C33, C34, C37, C38: 100nF; C_0603_1608Metric; Part # C0603C104J5RACTU; LCSC C14663
C25, C26: 2.2uF; C_0603_1608Metric; Part # GRM188R6YA225KA12D; LCSC C23630
C28, C44: 6.8pF; C_0603_1608Metric; LCSC C1679
C39: 22uF; C_0603_1608Metric; LCSC C59461
C100: 2.2uF; C_0805_2012Metric
D14: LED-GREEN; LED_0805_2012Metric; LCSC C2297
D16: SRV05-4; SOT-23-6; LCSC C85364
D17: B5819W; D_SOD-123; LCSC C8598
D19: LED-RED; LED_0603_1608Metric; LCSC C2286
D42: BAV70; SOT-23; LCSC C82479
FB1: FILTER; R_0603_1608Metric_Pad1.05x0.95mm_HandSolder; Part # BLM21PG221SN1D; LCSC C1034
FID1, FID2: Fiducial; Fiducial_0.5mm_Mask1mm; Part # DNP
J1: USB_B_Mini; USB-MINI-B-VERTICAL; LCSC C13453
J2: Conn_02x05_Odd_Even; PinSocket_2x05_P2.54mm_Vertical_SMD; Part # 95278-801B10LF
J7: TC2030; Tag-Connect_TC2030-IDC-NL_2x03_P1.27mm_Vertical
J19: Conn_01x06; JST_EH_B5B-EH-A_1x05_P2.50mm_Vertical
NT1: Net-Tie_2; Net-Tie_2_8.5mil
R43, R45: 10K; R_0603_1608Metric; Part # RMCF0603JT10K0; LCSC C25804
R47: 100K; R_0603_1608Metric; Part # RMCF0603JT100K; LCSC C25803
R48: 2.2k; R_0603_1608Metric; Part # RMCF0603FT2K20; LCSC C4190
R50: 1k; R_0603_1608Metric; Part # RMCF0603JJ1K00; LCSC C21190
SW1, SW2: SW_Push; SW_SPST_CK_RS282G05A3; LCSC C398054
SW3, SW4: SW_Push; SW_Push_SPST_NO_Alps_SKRK
U1: STM32H562VGT6; LQFP-100_14x14mm_P0.5mm; Part # STM32H562VGT6; LCSC C117815
U3: molex_48pin_MRE
U5: LM1117-3.3; SOT-223-3_TabPin2; LCSC C6186
X1: 8MHz 20pF; Crystal_SMD_5032-2Pin_5.0x3.2mm; LCSC C115962
Y2: 32768 Hz; Crystal_SMD_3215-2Pin_3.2x1.5mm; LCSC C32346

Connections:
/5V: D16.5, D17.1 (K), J2.1, J2.2, U3.J201, U3.J202, U5.3 (VI); also elsewhere on the board
/AT1_MCU: U1.23 (PA0); also elsewhere on the board
/AT2_MCU: U1.24 (PA1); also elsewhere on the board
/AT3_MCU: U1.25 (PA2); also elsewhere on the board
/AT4_MCU: U1.26 (PA3); also elsewhere on the board
/AV1_MCU: U1.15 (PC0); also elsewhere on the board
/AV2_MCU: U1.31 (PA6); also elsewhere on the board
/AV3_MCU: U1.32 (PA7); also elsewhere on the board
/AV4_MCU: U1.17 (PC2); also elsewhere on the board
/AV5_MCU: U1.18 (PC3); also elsewhere on the board
/AV6_MCU: U1.33 (PC4); also elsewhere on the board
/AV7_MCU: U1.34 (PC5); also elsewhere on the board
/AV8_MCU: U1.35 (PB0); also elsewhere on the board
/AV9_MCU: U1.36 (PB1); also elsewhere on the board
/AV10_MCU: U1.29 (PA4); also elsewhere on the board
/CAM_MCU: U1.30 (PA5); also elsewhere on the board
/CRANK: U1.63 (PC6); also elsewhere on the board
/CS_TLE: U1.86 (PD5); also elsewhere on the board
/FlashMemory/CS: U1.46 (PE15); also elsewhere on the board
/FlashMemory/SCK: U1.52 (PB13); also elsewhere on the board
/FlashMemory/SI: U1.54 (PB15); also elsewhere on the board
/FlashMemory/SO: U1.53 (PB14); also elsewhere on the board
/H-BRIDGE/DIR: U1.67 (PA8); also elsewhere on the board
/H-BRIDGE/DIS: U1.65 (PC8); also elsewhere on the board
/H-BRIDGE/PWM: U1.64 (PC7); also elsewhere on the board
/H-BRIDGE/SO: U1.66 (PC9); also elsewhere on the board
/MCU/BOOT0: R45.1, SW1.2, SW4.2, U1.94 (BOOT0)
/MCU/PA9: D14.2 (A), D16.4, D17.2 (A), J1.1 (VBUS), J19.4, NT1.2; also elsewhere on the board
/MCU/PA10: D16.1, J1.4 (ID), J19.1, U1.69 (PA10)
/MCU/PA13: J2.9, J7.2, U1.72 (PA13), U3.J209
/MCU/PA14: J2.5, J7.4, U1.76 (PA14), U3.J205
/MCU/PB2-BOOT1: U1.37 (PB2); also elsewhere on the board
/MCU/PB6: U1.92 (PB6); also elsewhere on the board
/MCU/PB7: U1.93 (PB7); also elsewhere on the board
/MCU/PB12: U1.51 (PB12); also elsewhere on the board
/MCU/PD0: U1.81 (PD0); also elsewhere on the board
/MCU/PD1: U1.82 (PD1); also elsewhere on the board
/MCU/PD2: U1.83 (PD2); also elsewhere on the board
/MCU/PD3: U1.84 (PD3); also elsewhere on the board
/MCU/PD4: U1.85 (PD4); also elsewhere on the board
/MCU/PD6: U1.87 (PD6); also elsewhere on the board
/MCU/PD7: U1.88 (PD7); also elsewhere on the board
/MCU/PD8: U1.55 (PD8); also elsewhere on the board
/MCU/PD9: U1.56 (PD9); also elsewhere on the board
/MCU/PD10: U1.57 (PD10); also elsewhere on the board
/MCU/PD11: U1.58 (PD11); also elsewhere on the board
/MCU/PE5: U1.4 (PE5); also elsewhere on the board
/MCU/PE6: U1.5 (PE6); also elsewhere on the board
/MCU/PE7: U1.38 (PE7); also elsewhere on the board
/MCU/PE8: U1.39 (PE8); also elsewhere on the board
/MCU/PE9: U1.40 (PE9); also elsewhere on the board
/MCU/PE10: U1.41 (PE10); also elsewhere on the board
/MCU/PE11: U1.42 (PE11); also elsewhere on the board
/MCU/PE12: U1.43 (PE12); also elsewhere on the board
/MCU/PE13: U1.44 (PE13); also elsewhere on the board
/MCU/PE14: U1.45 (PE14); also elsewhere on the board
/MCU/VBAT: D42.1 (A); also elsewhere on the board
/MCU/VDDA: C23.2, C24.2, C27.2, C29.2, FB1.2, U1.21 (VREF+), U1.22 (VDDA)
/MCU/Vrtc: D42.2 (A), U3.J31
/MCU/Vrtcc: D42.3 (K), U1.6 (VBAT)
/MCU/shield: C37.1, J1.6 (Shield), R47.1
/PA15: U1.77 (PA15); also elsewhere on the board
/PB8: U1.95 (PB8); also elsewhere on the board
/PB9: U1.96 (PB9); also elsewhere on the board
/PB10: U1.47 (PB10); also elsewhere on the board
/PC10: U1.78 (PC10); also elsewhere on the board
/PC11: U1.79 (PC11); also elsewhere on the board
/PC12: U1.80 (PC12); also elsewhere on the board
/PC13: U1.7 (PC13); also elsewhere on the board
/PD12: U1.59 (PD12); also elsewhere on the board
/PD13: U1.60 (PD13); also elsewhere on the board
/PD14: U1.61 (PD14); also elsewhere on the board
/PD15: U1.62 (PD15); also elsewhere on the board
/PE0: U1.97 (PE0); also elsewhere on the board
/PE2: U1.1 (PE2); also elsewhere on the board
/PE3: U1.2 (PE3); also elsewhere on the board
/PE4: U1.3 (PE4); also elsewhere on the board
/RST: C20.2, J2.10, J7.3, R43.2, SW2.1, SW3.1, U1.14 (NRST), U3.J210; also elsewhere on the board
/SCK: J2.6, J7.6, U1.89 (PB3), U3.J206; also elsewhere on the board
/SI: U1.91 (PB5); also elsewhere on the board
/SO: U1.90 (PB4); also elsewhere on the board
/USB_D+: D16.3, J1.3 (D+), J19.3, U1.71 (PA12); also elsewhere on the board
/USB_D-: D16.6, J1.2 (D-), J19.2, U1.70 (PA11); also elsewhere on the board
/Vbat_MCU: U1.16 (PC1); also elsewhere on the board
unnamed: C21.1, U1.12 (PH0), X1.2
unnamed: C22.1, U1.13 (PH1), X1.1
unnamed: C28.1, U1.8 (PC14), Y2.1
unnamed: C44.2, U1.9 (PC15), Y2.2
unnamed: D14.1 (K), R48.2
unnamed: D19.1 (K), R50.2
unnamed: NT1.1, U1.68 (PA9)

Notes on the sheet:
SWD
USB bulk head connector USB UB-20PMFP-LC7002 Cover / Cap CAP-WADMLP_ _
http://www.crystek.com/documents/appnotes/Pierce-GateIntroduction.pdf PCB per predictions with SaturnPCB has less then 3.5pF traces, STM32 pins assumed 5pF ESR = 80ohms max??? Rf = 2meg could be between 1meg and 10meg. Cload should be 8pF per XTAL datasheet Cload = ([Cin+C1][C2+Cout])/(Cin+C1+C2_Co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
3.3v
USB power
USB ESD protection
OpenEMS: STM32H562VGTx LQFP100 drop-in over F407. Pad diffs: 19=VSSA (was VDD), 20=VREF- (was VSSA), 48/98=VCAP (was PB11/PE1), 49=VSS (was VCAP_1), 73=VDDUSB (was VCAP_2). INJEN=PE14 (not PE1). See docs/hw/mcu_f407_to_h562_pin_map.md
H562: pad19 VSSA — DISCONNECT from VDD rail; tie AGND (PCB rework if rail shared)
H562: pad73=VDDUSB — join +3V3/VDD (C26 2.2uF stays as decap)
H562: pad49=VSS — join GND (was VCAP_1)
H562: pad48=VCAP — C100 2.2uF to GND (confirmed WeAct H562)
H562: pad98=VCAP — C25 2.2uF to GND (confirmed WeAct); INJEN=PE14

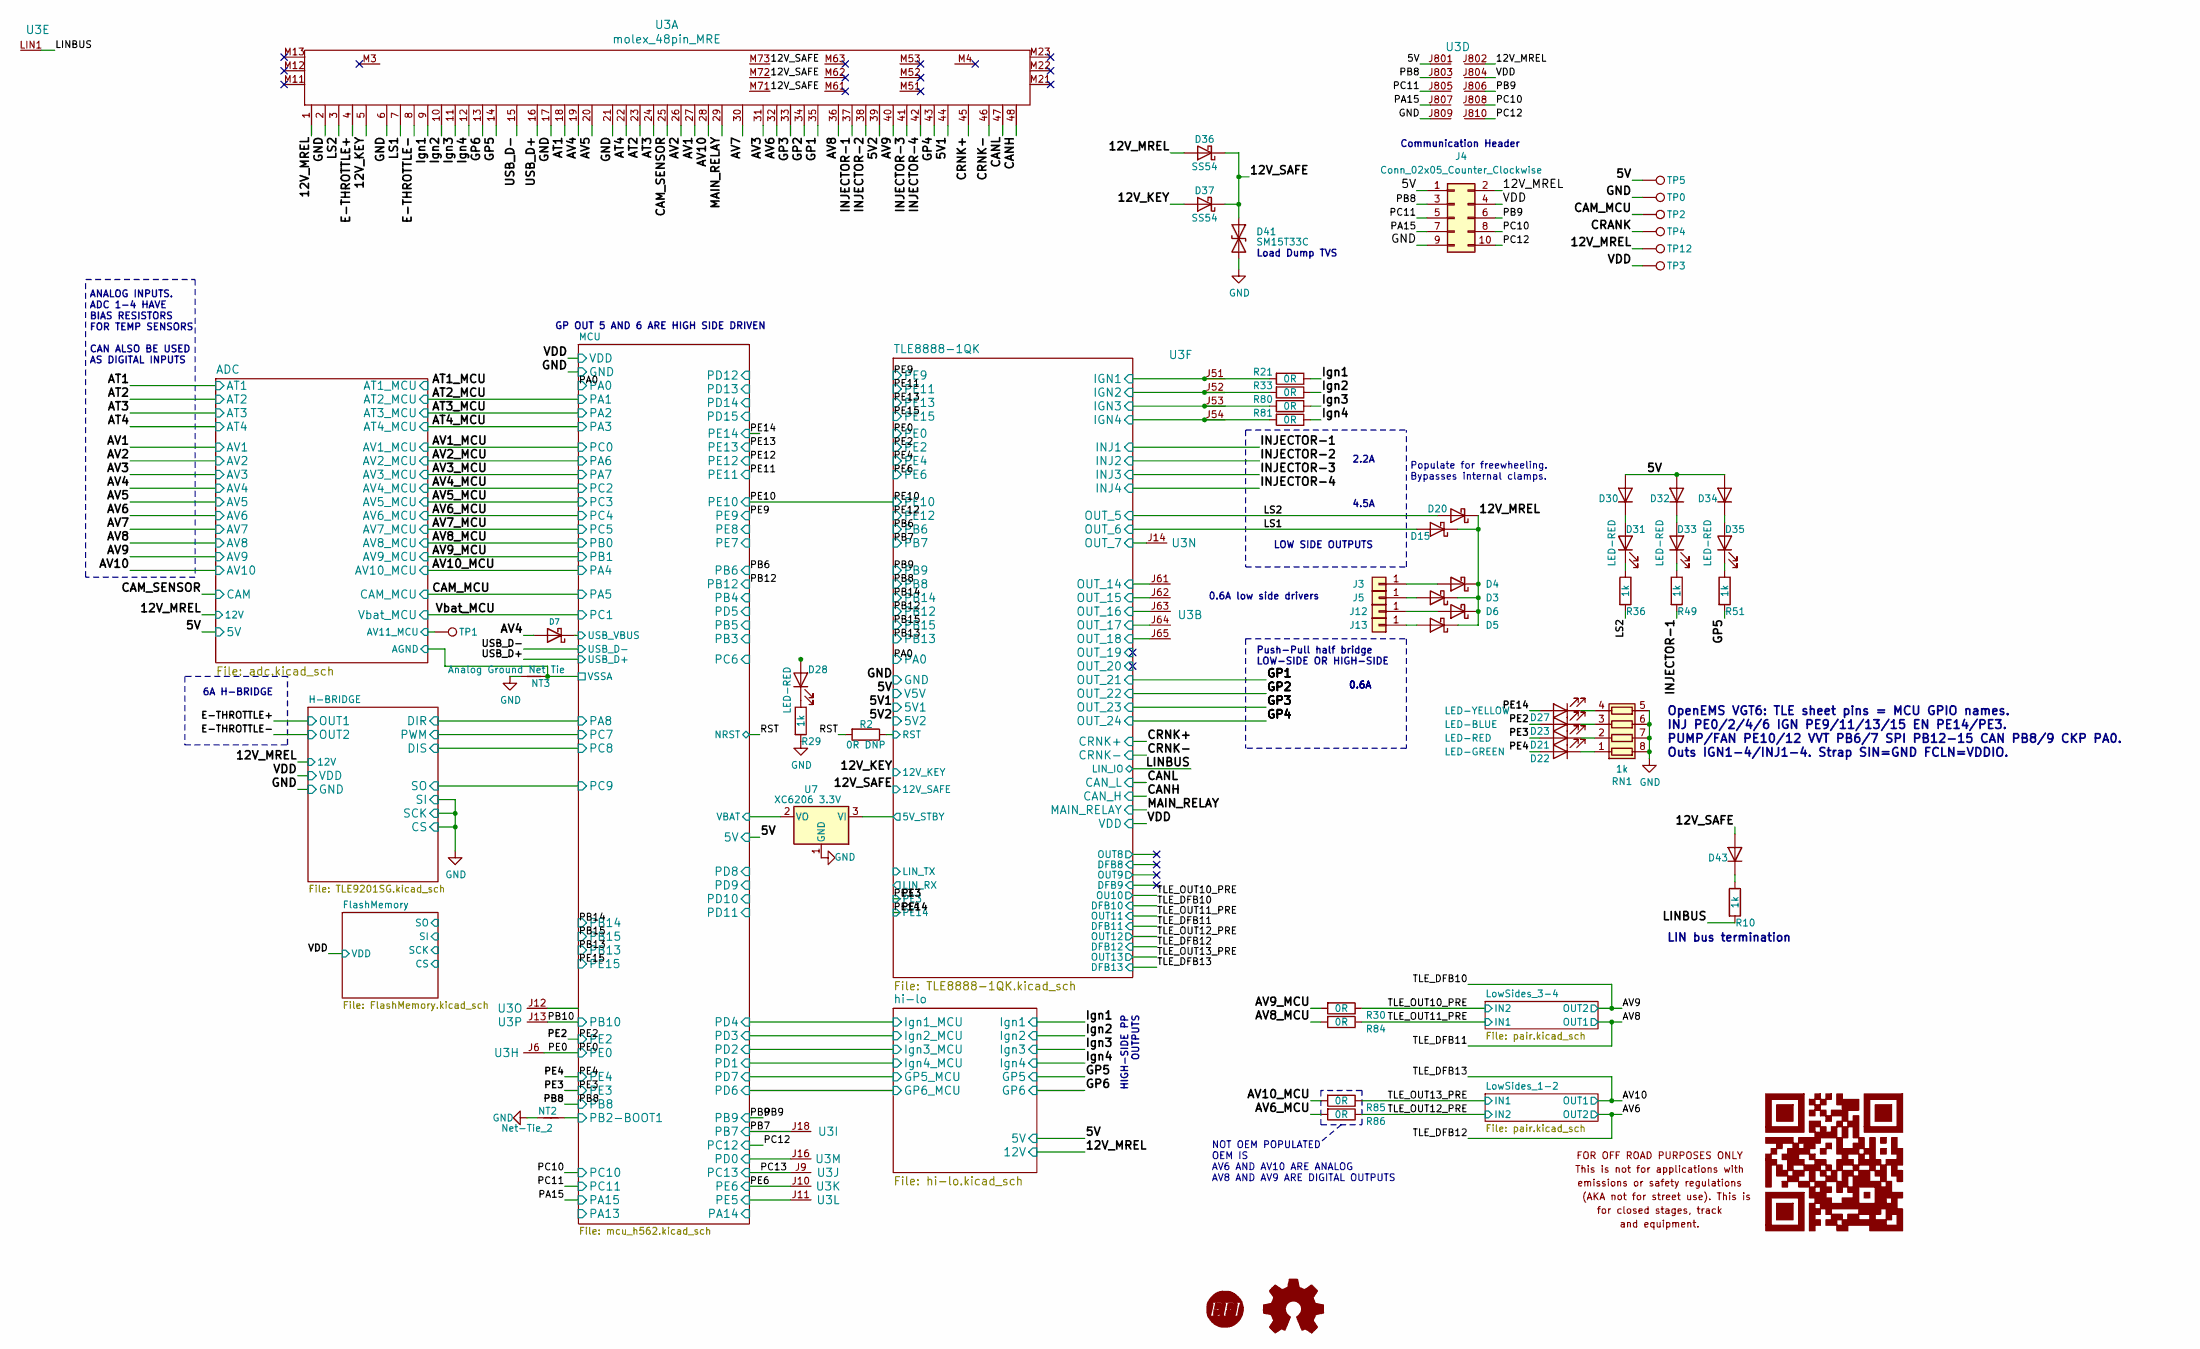
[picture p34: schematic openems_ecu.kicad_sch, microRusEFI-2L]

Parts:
D3, D4, D5, D6, D15, D20, D36, D37: SS54; D_SMA; LCSC C22452
D7: B5819W; D_SOD-123; LCSC C8598
D21: LED-RED; LED_0805_2012Metric; LCSC C84256
D22: LED-GREEN; LED_0805_2012Metric; LCSC C2297
D23: LED-BLUE; LED_0805_2012Metric; LCSC C2293
D27: LED-YELLOW; LED_0805_2012Metric; LCSC C2296
D28, D31, D33, D35: LED-RED; LED_0603_1608Metric; LCSC C2286
D30, D32, D34, D43: 1N4148WS; D_SOD-323; Part # NSR0530HT; LCSC C2128
D41: SM15T33C; D_SMC; LCSC C133707
G1: Disclaimer; Off_Road_Disclaimer
J3, J5, J12, J13: Conn_01x01; Pin_D0.7mm_L6.5mm_W1.8mm_FlatFork
J4: Conn_02x05_Counter_Clockwise; PinHeader_2x05_P2.54mm_Vertical_SMD
LOGO1: DNP; OSHW-Logo2_7.3x6mm_SilkScreen; Part # DNP
LOGO2: DNP; LOGO; Part # DNP
LOGO3: LOGO; MRE_QR_code
NT2: Net-Tie_2; Net-Tie_2_8.5mil
NT3: Analog Ground Net Tie; NetTie-2_SMD_Pad0.5mm
R2: 0R DNP; R_0603_1608Metric; Part # DNP
R10: 1k; R_1206_3216Metric; LCSC C4410
R21, R30, R33, R80, R81, R84: 0R; R_0603_1608Metric; Part # 0603WAF0000T5E; LCSC C21189
R29, R36, R49, R51: 1k; R_0603_1608Metric; Part # RMCF0603JJ1K00; LCSC C21190
R85: 0R; R_0603_1608Metric; Part # 0603WAF0000T5E
R86: 0R; R_0805_2012Metric
RN1: 1k; R_Array_Convex_4x0603; Part # CAT16-1001F4LF; LCSC C20197
TP0, TP3: GND; TestPoint_Pad_D2.0mm; Part # DNP
TP1, TP2, TP4: TP; TestPoint_Pad_D2.0mm; Part # DNP
TP5, TP12: 5V; TestPoint_Pad_D2.0mm; Part # DNP
U3: molex_48pin_MRE; Molex_48_MRE; Part # 500762-0481
U7: XC6206 3.3V; SOT-23; Part # XC6206P332MR; LCSC C5446

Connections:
/5V: D30.2 (A), D32.2 (A), D34.2 (A), J4.1, TP5.1, U3.J801; also elsewhere on the board
/5V1: U3.44; also elsewhere on the board
/5V2: U3.39; also elsewhere on the board
/12V_KEY: D37.2 (A), U3.5; also elsewhere on the board
/12V_MREL: D3.1 (K), D4.1 (K), D5.1 (K), D6.1 (K), D15.1 (K), D20.1 (K), D36.2 (A), J4.2, TP12.1, U3.1, U3.J802; also elsewhere on the board
/12V_SAFE: D36.1 (K), D37.1 (K), D41.1 (A1), D43.2 (A), U3.M71, U3.M72, U3.M73; also elsewhere on the board
/ADC/AV11_MCU: TP1.1; also elsewhere on the board
/AT1: U3.18; also elsewhere on the board
/AT2: U3.23; also elsewhere on the board
/AT3: U3.24; also elsewhere on the board
/AT4: U3.22; also elsewhere on the board
/AV1: U3.27; also elsewhere on the board
/AV2: U3.26; also elsewhere on the board
/AV3: U3.31; also elsewhere on the board
/AV4: D7.2 (A), U3.19; also elsewhere on the board
/AV5: U3.20; also elsewhere on the board
/AV6: U3.32; also elsewhere on the board
/AV6_MCU: R86.2; also elsewhere on the board
/AV7: U3.30; also elsewhere on the board
/AV8: U3.36; also elsewhere on the board
/AV8_MCU: R84.2; also elsewhere on the board
/AV9: U3.40; also elsewhere on the board
/AV9_MCU: R30.2; also elsewhere on the board
/AV10: U3.28; also elsewhere on the board
/AV10_MCU: R85.2; also elsewhere on the board
/CAM_MCU: TP2.1; also elsewhere on the board
/CAM_SENSOR: U3.25; also elsewhere on the board
/CANH: U3.48; also elsewhere on the board
/CANL: U3.47; also elsewhere on the board
/CRANK: D28.2 (A), TP4.1; also elsewhere on the board
/CRNK+: U3.45; also elsewhere on the board
/CRNK-: U3.46; also elsewhere on the board
/E-THROTTLE+: U3.4; also elsewhere on the board
/E-THROTTLE-: U3.8; also elsewhere on the board
/GP1: U3.35; also elsewhere on the board
/GP2: U3.34; also elsewhere on the board
/GP3: U3.33; also elsewhere on the board
/GP4: U3.43; also elsewhere on the board
/GP5: R51.2, U3.14; also elsewhere on the board
/GP6: U3.13; also elsewhere on the board
/INJECTOR-1: R49.2, U3.37; also elsewhere on the board
/INJECTOR-2: U3.38; also elsewhere on the board
/INJECTOR-3: U3.41; also elsewhere on the board
/INJECTOR-4: U3.42; also elsewhere on the board
/Ign1: R21.1, U3.9; also elsewhere on the board
/Ign2: R33.1, U3.10; also elsewhere on the board
/Ign3: R80.1, U3.11; also elsewhere on the board
/Ign4: R81.1, U3.12; also elsewhere on the board
/LINBUS: R10.2, U3.LIN1; also elsewhere on the board
/LS1: D15.2 (A), U3.7; also elsewhere on the board
/LS2: D20.2 (A), R36.2, U3.3; also elsewhere on the board
/MAIN_RELAY: U3.29; also elsewhere on the board
/MCU/PA9: D7.1 (K); also elsewhere on the board
/MCU/PB2-BOOT1: NT2.2; also elsewhere on the board
/MCU/PB7: U3.J18; also elsewhere on the board
/MCU/PD0: U3.J16; also elsewhere on the board
/MCU/PE5: U3.J11; also elsewhere on the board
/MCU/PE6: U3.J10; also elsewhere on the board
/MCU/VBAT: U7.2 (VO); also elsewhere on the board
/PA15: J4.7, U3.J807; also elsewhere on the board
/PB8: J4.3, U3.J803; also elsewhere on the board
/PB9: J4.6, U3.J806; also elsewhere on the board
/PB10: U3.J13; also elsewhere on the board
/PB11: U3.J12
/PC10: J4.8, U3.J808; also elsewhere on the board
/PC11: J4.5, U3.J805; also elsewhere on the board
/PC12: J4.10, U3.J810; also elsewhere on the board
/PC13: U3.J9; also elsewhere on the board
/PE0: U3.J6; also elsewhere on the board
/PE1: D27.2 (A)
/PE2: D23.2 (A); also elsewhere on the board
/PE3: D21.2 (A); also elsewhere on the board
/PE4: D22.2 (A); also elsewhere on the board
/RST: R2.2; also elsewhere on the board
/TLE8888-1QK/5V_STBY: U7.3 (VI); also elsewhere on the board
/TLE8888-1QK/IGN_OUT_1: R21.2, U3.J51; also elsewhere on the board
/TLE8888-1QK/IGN_OUT_2: R33.2, U3.J52; also elsewhere on the board
/TLE8888-1QK/IGN_OUT_3: R80.2, U3.J53; also elsewhere on the board
/TLE8888-1QK/IGN_OUT_4: R81.2, U3.J54; also elsewhere on the board
/TLE8888-1QK/OUT_7: U3.J14; also elsewhere on the board
/TLE8888-1QK/OUT_14: U3.J61; also elsewhere on the board
/TLE8888-1QK/OUT_15: U3.J62; also elsewhere on the board
/TLE8888-1QK/OUT_16: U3.J63; also elsewhere on the board
/TLE8888-1QK/OUT_17: U3.J64; also elsewhere on the board
/TLE8888-1QK/OUT_18: U3.J65; also elsewhere on the board
/TLE8888-1QK/RST: R2.1; also elsewhere on the board
/TLE_OUT10_PRE: R30.1; also elsewhere on the board
/TLE_OUT11_PRE: R84.1; also elsewhere on the board
/TLE_OUT12_PRE: R86.1; also elsewhere on the board
/TLE_OUT13_PRE: R85.1; also elsewhere on the board
/USB_D+: U3.16; also elsewhere on the board
/USB_D-: U3.15; also elsewhere on the board
unnamed: D3.2 (A), J5.1
unnamed: D4.2 (A), J3.1
unnamed: D5.2 (A), J13.1
unnamed: D6.2 (A), J12.1
unnamed: D21.1 (K), RN1.2 (R2.1)
unnamed: D22.1 (K), RN1.1 (R1.1)
unnamed: D23.1 (K), RN1.3 (R3.1)
unnamed: D27.1 (K), RN1.4 (R4.1)
unnamed: D28.1 (K), R29.1
unnamed: D30.1 (K), D31.2 (A)
unnamed: D31.1 (K), R36.1
unnamed: D32.1 (K), D33.2 (A)
unnamed: D33.1 (K), R49.1
unnamed: D34.1 (K), D35.2 (A)
unnamed: D35.1 (K), R51.1
unnamed: D43.1 (K), R10.1

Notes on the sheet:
GP OUT 5 AND 6 ARE HIGH SIDE DRIVEN
6A H-BRIDGE
Load Dump TVS
0.6A
0.6A low side drivers
NOT OEM POPULATED OEM IS AV6 AND AV10 ARE ANALOG AV8 AND AV9 ARE DIGITAL OUTPUTS
Communication Header
ANALOG INPUTS. ADC 1-4 HAVE BIAS RESISTORS FOR TEMP SENSORS CAN ALSO BE USED AS DIGITAL INPUTS
LOW SIDE OUTPUTS
Push-Pull half bridge LOW-SIDE OR HIGH-SIDE
4.5A
OpenEMS VGT6: TLE sheet pins = MCU GPIO names. INJ PE0/2/4/6 IGN PE9/11/13/15 EN PE14/PE3. PUMP/FAN PE10/12 VVT PB6/7 SPI PB12-15 CAN PB8/9 CKP PA0. Outs IGN1-4/INJ1-4. Strap SIN=GND FCLN=VDDIO.
HIGH-SIDE PP OUTPUTS
Populate for freewheeling. Bypasses internal clamps.
2.2A
LIN bus termination

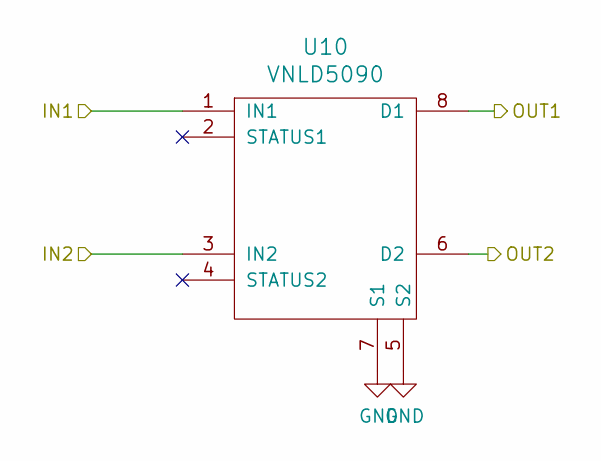
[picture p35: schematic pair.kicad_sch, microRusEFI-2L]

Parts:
U10: VNLD5090; SO-8_3.9x4.9mm_P1.27mm; LCSC C377942

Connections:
/AV8: U10.8 (D1); also elsewhere on the board
/AV9: U10.6 (D2); also elsewhere on the board
/TLE_OUT10_PRE: U10.3 (IN2); also elsewhere on the board
/TLE_OUT11_PRE: U10.1 (IN1); also elsewhere on the board

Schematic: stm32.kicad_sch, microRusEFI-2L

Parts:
C20, C29: 10nF; C_0603_1608Metric; Part # C0603C103K1RACTU; LCSC C57112
C21, C22: 18pF; C_0603_1608Metric; Part # CL10C180JB8NNNC; LCSC C1647
C23, C27, C36: 1uF; C_0603_1608Metric; Part # UMK107BJ105KA-T; LCSC C15849
C24, C30, C31, C32, C33, C34, C37, C38: 100nF; C_0603_1608Metric; Part # C0603C104J5RACTU; LCSC C14663
C25, C26: 2.2uF; C_0603_1608Metric; Part # GRM188R6YA225KA12D; LCSC C23630
C28, C44: 6.8pF; C_0603_1608Metric; LCSC C1679
C39: 22uF; C_0603_1608Metric; LCSC C59461
D14: LED-GREEN; LED_0805_2012Metric; LCSC C2297
D16: SRV05-4; SOT-23-6; LCSC C85364
D17: B5819W; D_SOD-123; LCSC C8598
D19: LED-RED; LED_0603_1608Metric; LCSC C2286
D42: BAV70; SOT-23; LCSC C82479
FB1: FILTER; R_0603_1608Metric_Pad1.05x0.95mm_HandSolder; Part # BLM21PG221SN1D; LCSC C1034
FID1, FID2: Fiducial; Fiducial_0.5mm_Mask1mm; Part # DNP
J1: USB_B_Mini; USB-MINI-B-VERTICAL; LCSC C13453
J2: Conn_02x05_Odd_Even; PinSocket_2x05_P2.54mm_Vertical_SMD; Part # 95278-801B10LF
J7: TC2030; Tag-Connect_TC2030-IDC-NL_2x03_P1.27mm_Vertical
J19: Conn_01x06; JST_EH_B5B-EH-A_1x05_P2.50mm_Vertical
NT1: Net-Tie_2; Net-Tie_2_8.5mil
R43, R45: 10K; R_0603_1608Metric; Part # RMCF0603JT10K0; LCSC C25804
R47: 100K; R_0603_1608Metric; Part # RMCF0603JT100K; LCSC C25803
R48: 2.2k; R_0603_1608Metric; Part # RMCF0603FT2K20; LCSC C4190
R50: 1k; R_0603_1608Metric; Part # RMCF0603JJ1K00; LCSC C21190
SW1, SW2: SW_Push; SW_SPST_CK_RS282G05A3; LCSC C398054
SW3, SW4: SW_Push; SW_Push_SPST_NO_Alps_SKRK
U1: STM32F427VGT6; LQFP-100_14x14mm_P0.5mm; Part # STM32F427VGT6; LCSC C117815
U3: molex_48pin_MRE
U5: LM1117-3.3; SOT-223-3_TabPin2; LCSC C6186
X1: 8MHz 20pF; Crystal_SMD_5032-2Pin_5.0x3.2mm; LCSC C115962
Y2: 32768 Hz; Crystal_SMD_3215-2Pin_3.2x1.5mm; LCSC C32346

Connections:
/5V: D16.5, D17.1 (K), J2.1, J2.2, U3.J201, U3.J202, U5.3 (VI); also elsewhere on the board
/AT1_MCU: U1.23 (PA0); also elsewhere on the board
/AT2_MCU: U1.24 (PA1); also elsewhere on the board
/AT3_MCU: U1.25 (PA2); also elsewhere on the board
/AT4_MCU: U1.26 (PA3); also elsewhere on the board
/AV1_MCU: U1.15 (PC0); also elsewhere on the board
/AV2_MCU: U1.31 (PA6); also elsewhere on the board
/AV3_MCU: U1.32 (PA7); also elsewhere on the board
/AV4_MCU: U1.17 (PC2); also elsewhere on the board
/AV5_MCU: U1.18 (PC3); also elsewhere on the board
/AV6_MCU: U1.33 (PC4); also elsewhere on the board
/AV7_MCU: U1.34 (PC5); also elsewhere on the board
/AV8_MCU: U1.35 (PB0); also elsewhere on the board
/AV9_MCU: U1.36 (PB1); also elsewhere on the board
/AV10_MCU: U1.29 (PA4); also elsewhere on the board
/CAM_MCU: U1.30 (PA5); also elsewhere on the board
/CRANK: U1.63 (PC6); also elsewhere on the board
/CS_TLE: U1.86 (PD5); also elsewhere on the board
/FlashMemory/CS: U1.46 (PE15); also elsewhere on the board
/FlashMemory/SCK: U1.52 (PB13); also elsewhere on the board
/FlashMemory/SI: U1.54 (PB15); also elsewhere on the board
/FlashMemory/SO: U1.53 (PB14); also elsewhere on the board
/H-BRIDGE/DIR: U1.67 (PA8); also elsewhere on the board
/H-BRIDGE/DIS: U1.65 (PC8); also elsewhere on the board
/H-BRIDGE/PWM: U1.64 (PC7); also elsewhere on the board
/H-BRIDGE/SO: U1.66 (PC9); also elsewhere on the board
/MCU/BOOT0: R45.1, SW1.2, SW4.2, U1.94 (BOOT0)
/MCU/PA9: D14.2 (A), D16.4, D17.2 (A), J1.1 (VBUS), J19.4, NT1.2; also elsewhere on the board
/MCU/PA10: D16.1, J1.4 (ID), J19.1, U1.69 (PA10)
/MCU/PA13: J2.9, J7.2, U1.72 (PA13), U3.J209
/MCU/PA14: J2.5, J7.4, U1.76 (PA14), U3.J205
/MCU/PB2-BOOT1: U1.37 (PB2); also elsewhere on the board
/MCU/PB6: U1.92 (PB6); also elsewhere on the board
/MCU/PB7: U1.93 (PB7); also elsewhere on the board
/MCU/PB12: U1.51 (PB12); also elsewhere on the board
/MCU/PD0: U1.81 (PD0); also elsewhere on the board
/MCU/PD1: U1.82 (PD1); also elsewhere on the board
/MCU/PD2: U1.83 (PD2); also elsewhere on the board
/MCU/PD3: U1.84 (PD3); also elsewhere on the board
/MCU/PD4: U1.85 (PD4); also elsewhere on the board
/MCU/PD6: U1.87 (PD6); also elsewhere on the board
/MCU/PD7: U1.88 (PD7); also elsewhere on the board
/MCU/PD8: U1.55 (PD8); also elsewhere on the board
/MCU/PD9: U1.56 (PD9); also elsewhere on the board
/MCU/PD10: U1.57 (PD10); also elsewhere on the board
/MCU/PD11: U1.58 (PD11); also elsewhere on the board
/MCU/PE5: U1.4 (PE5); also elsewhere on the board
/MCU/PE6: U1.5 (PE6); also elsewhere on the board
/MCU/PE7: U1.38 (PE7); also elsewhere on the board
/MCU/PE8: U1.39 (PE8); also elsewhere on the board
/MCU/PE9: U1.40 (PE9); also elsewhere on the board
/MCU/PE10: U1.41 (PE10); also elsewhere on the board
/MCU/PE11: U1.42 (PE11); also elsewhere on the board
/MCU/PE12: U1.43 (PE12); also elsewhere on the board
/MCU/PE13: U1.44 (PE13); also elsewhere on the board
/MCU/PE14: U1.45 (PE14); also elsewhere on the board
/MCU/VBAT: D42.1 (A); also elsewhere on the board
/MCU/VDDA: C23.2, C24.2, C27.2, C29.2, FB1.2, U1.21 (VREF+), U1.22 (VDDA)
/MCU/Vrtc: D42.2 (A), U3.J31
/MCU/Vrtcc: D42.3 (K), U1.6 (VBAT)
/MCU/shield: C37.1, J1.6 (Shield), R47.1
/PA15: U1.77 (PA15); also elsewhere on the board
/PB8: U1.95 (PB8); also elsewhere on the board
/PB9: U1.96 (PB9); also elsewhere on the board
/PB10: U1.47 (PB10); also elsewhere on the board
/PC10: U1.78 (PC10); also elsewhere on the board
/PC11: U1.79 (PC11); also elsewhere on the board
/PC12: U1.80 (PC12); also elsewhere on the board
/PC13: U1.7 (PC13); also elsewhere on the board
/PD12: U1.59 (PD12); also elsewhere on the board
/PD13: U1.60 (PD13); also elsewhere on the board
/PD14: U1.61 (PD14); also elsewhere on the board
/PD15: U1.62 (PD15); also elsewhere on the board
/PE0: U1.97 (PE0); also elsewhere on the board
/PE2: U1.1 (PE2); also elsewhere on the board
/PE3: U1.2 (PE3); also elsewhere on the board
/PE4: U1.3 (PE4); also elsewhere on the board
/RST: C20.2, J2.10, J7.3, R43.2, SW2.1, SW3.1, U1.14 (NRST), U3.J210; also elsewhere on the board
/SCK: J2.6, J7.6, U1.89 (PB3), U3.J206; also elsewhere on the board
/SI: U1.91 (PB5); also elsewhere on the board
/SO: U1.90 (PB4); also elsewhere on the board
/USB_D+: D16.3, J1.3 (D+), J19.3, U1.71 (PA12); also elsewhere on the board
/USB_D-: D16.6, J1.2 (D-), J19.2, U1.70 (PA11); also elsewhere on the board
/Vbat_MCU: U1.16 (PC1); also elsewhere on the board
unnamed: C21.1, U1.12 (PH0), X1.2
unnamed: C22.1, U1.13 (PH1), X1.1
unnamed: C28.1, U1.8 (PC14), Y2.1
unnamed: C44.2, U1.9 (PC15), Y2.2
unnamed: D14.1 (K), R48.2
unnamed: D19.1 (K), R50.2
unnamed: NT1.1, U1.68 (PA9)

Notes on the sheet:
SWD
USB bulk head connector USB UB-20PMFP-LC7002 Cover / Cap CAP-WADMLP_ _
http://www.crystek.com/documents/appnotes/Pierce-GateIntroduction.pdf PCB per predictions with SaturnPCB has less then 3.5pF traces, STM32 pins assumed 5pF ESR = 80ohms max??? Rf = 2meg could be between 1meg and 10meg. Cload should be 8pF per XTAL datasheet Cload = ([Cin+C1][C2+Cout])/(Cin+C1+C2_Co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
3.3v
USB power
USB ESD protection

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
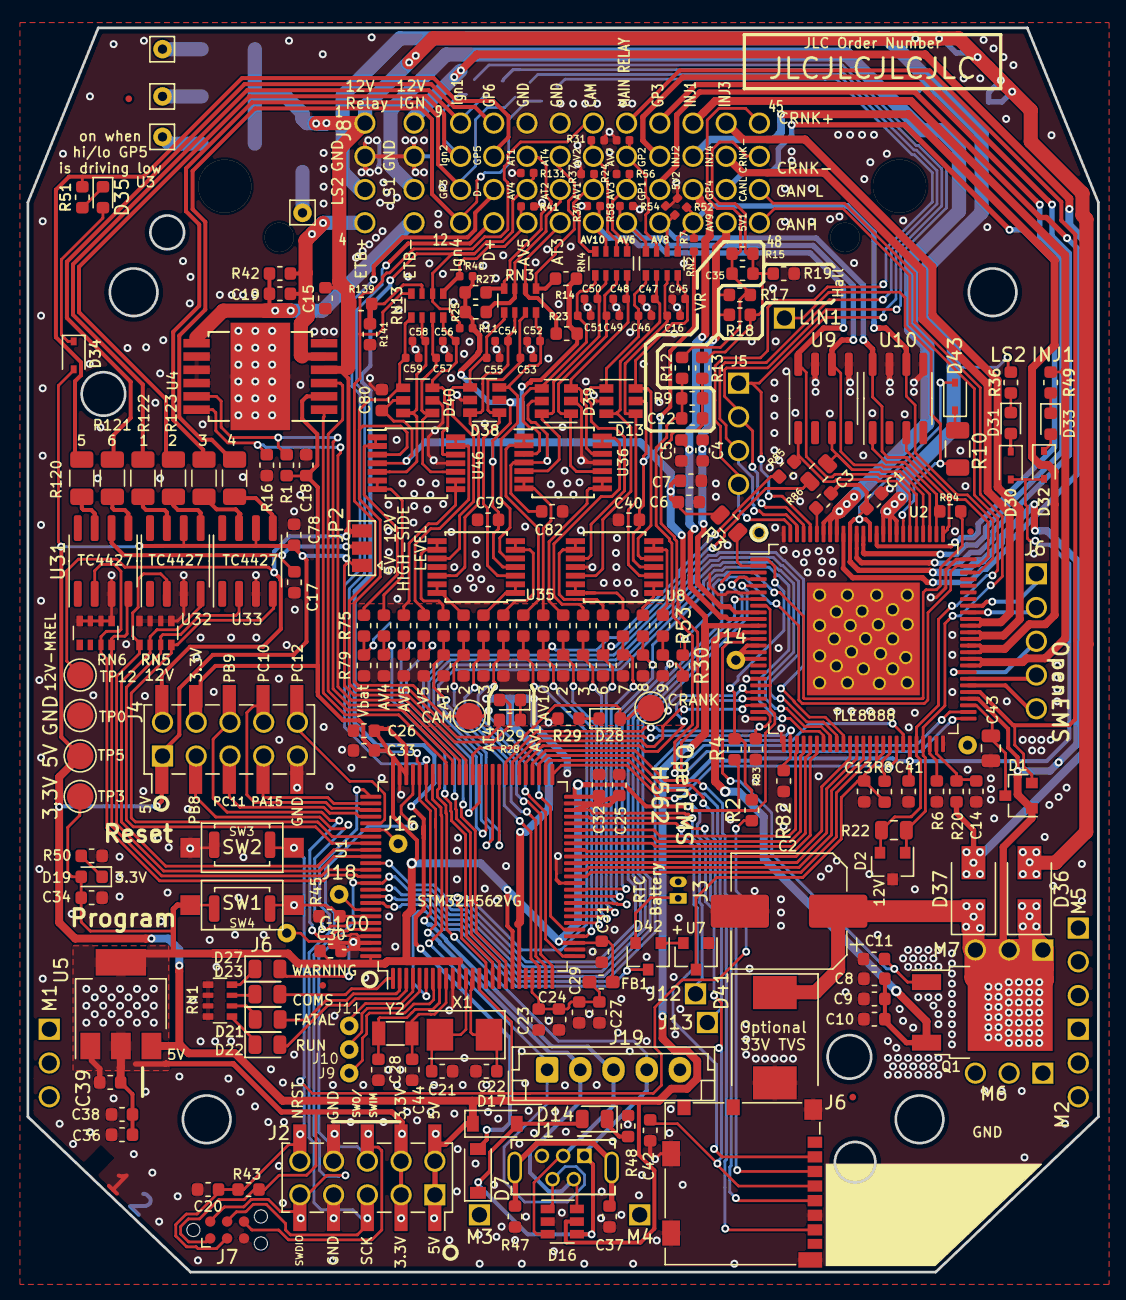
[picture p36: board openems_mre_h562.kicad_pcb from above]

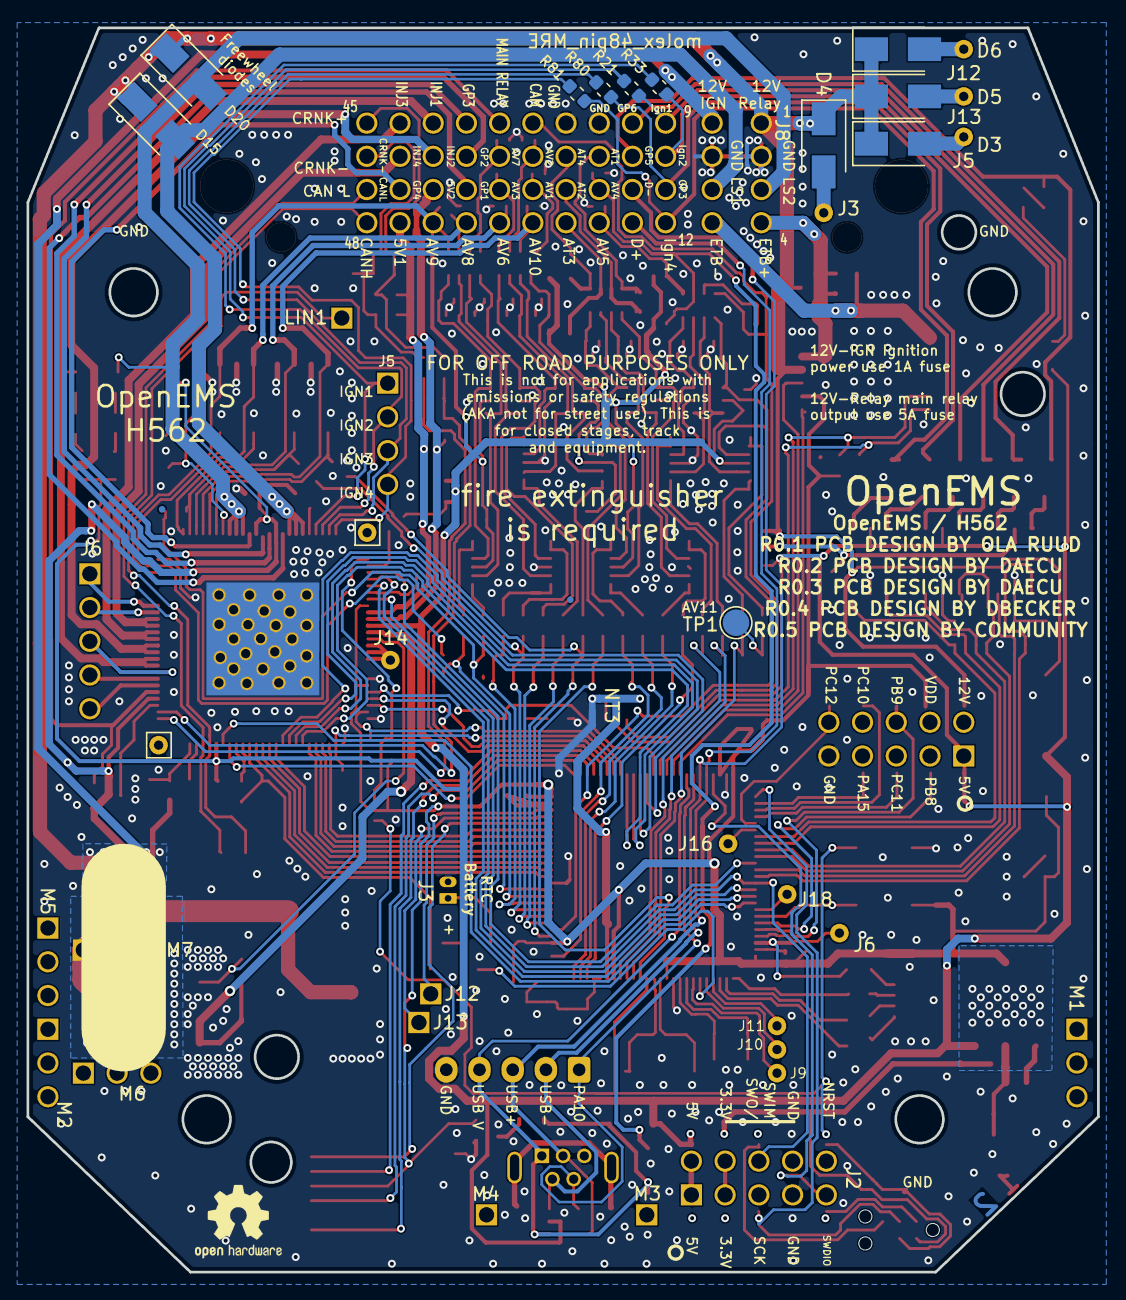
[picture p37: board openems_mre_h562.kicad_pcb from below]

Board: 2 copper layers, 80.6 x 93.7 mm, 254 parts (18 on the bottom side), 223 nets.

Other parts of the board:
U9: VNLD5090; SO-8_3.9x4.9mm_P1.27mm

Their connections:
/AV6: U9.6 (D2); also elsewhere on the board
/AV10: U9.8 (D1); also elsewhere on the board
/TLE_OUT12_PRE: U9.3 (IN2); also elsewhere on the board
/TLE_OUT13_PRE: U9.1 (IN1); also elsewhere on the board

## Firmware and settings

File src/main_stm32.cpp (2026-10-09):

// =============================================================================
// OpenEMS — src/main_stm32.cpp
// STM32H562RGT6 (ARM Cortex-M33 @ 250 MHz)
//
// Entry point STM32H562 do firmware.
//
// Configuracao principal:
//   - PLL 250 MHz via system_stm32_init()
//   - millis() provido por SysTick_Handler em system.cpp
//   - iwdg_kick() alimenta o watchdog IWDG
//   - SysTick fornece millis()/micros()
//   - NVIC setup usa IRQs do STM32H562 (TIM5 para CKP; TIM2/TIM1 são OC por hardware)
//   - SysTick e IWDG já inicializados em system_stm32_init()
//   - nvm_flush_adaptive_maps() no slot 500ms (Flash Bank2)
// =============================================================================

#if defined(EMS_HOST_TEST)

int main() { return 0; }

#elif defined(TARGET_STM32H562)  // ── target STM32H562 ─────────────────────

#include <cstdint>
#include <cstring>

#include "engine/math_utils.h"

#include "hal/stm32h562/system.h"
#include "hal/stm32h562/regs.h"
#include "hal/stm32h562/usb_cdc.h"
#include "hal/uart.h"

#include "app/can_stack.h"
#include "app/can_rx_map.h"
#include "app/nvm_boot.h"
#include "app/ui_protocol.h"
#include "drv/ckp.h"
#include "drv/sensors.h"
#include "engine/auxiliaries.h"
#include "engine/calibration.h"
#include "engine/constants.h"
#include "engine/cut_reason.h"
#include "engine/map_window.h"
#include "engine/vehicle_inputs.h"
#include "engine/ecu_sched.h"
#include "engine/engine_calc.h"
#include "engine/engine_config.h"
#include "engine/etb_control.h"
#include "engine/etb_autocal.h"
#include "hal/etb_driver.h"
#include "engine/fuel_calc.h"
#include "engine/ign_calc.h"
#include "engine/knock.h"
#include "engine/limp_gating.h"
#include "engine/map_estimator.h"
#include "engine/output_test.h"
#include "engine/diagnostic_manager.h"
#include "engine/misfire_detect.h"
#include "engine/quick_crank.h"
#include "engine/torque_manager.h"
#include "engine/transient_fuel.h"
#include "engine/spark_skip.h"
#include "engine/xtau_autocalib.h"
#include "engine/ewg_control.h"
#include "hal/adc.h"
#include "hal/can.h"
#include "hal/flash.h"
#include "hal/out_pins.h"
#include "hal/flex_fuel.h"
#include "hal/timer.h"

// =============================================================================
// Estado de background (do firmware)
// =============================================================================

static constexpr uint16_t kCalibPageBytes = 512u;
alignas(4) static uint8_t g_calib_page0[kCalibPageBytes];
static bool                g_calib_dirty  = false;

volatile uint32_t g_flash_write_faults = 0u; // FIX: fault counter para falhas de escrita NVM


static int8_t  g_last_advance_deg = 0;
static int16_t g_last_advance_x10 = 0;
// Spark retard from torque manager (TC/launch), updated in 2 ms ETB slot.
static int16_t g_torque_spark_retard_deg = 0;
static uint8_t g_last_pw_ms_x10   = 0u;
static int8_t  g_last_stft_pct    = 0;
static uint8_t g_last_lambda_target_d4 = 0u;
// MAP fundido do último tick de 2ms — fonte única p/ os consumidores de 100ms
// (STFT/alvo λ): usar o sensor cru ali dava alvo≠combustível na fronteira de célula.
static uint16_t g_last_map_fused_x100 = 0u;
static int8_t  g_last_ltft_pct    = 0;

static constexpr uint32_t kLimpRpmLimit_x10 = 30000u;
static bool g_limp_active = false;
// DIAG rev-limit: conta bordas de subida (false→true) do rev-limiter e latcha o
// rpm_x10 que o disparou. Suspeita: glitch fantasma de rpm_x10 (corrida ISR↔main)
// dispara o limiter ao ralenti → spikes de PW=0 de 1 loop. Expostos no dump 'D'.
uint32_t g_dbg_rev_limit_trips = 0u;
uint32_t g_dbg_rev_limit_rpm_x10 = 0u;   // último rpm_x10 que armou o trip
uint32_t g_dbg_rev_limit_rpm_max = 0u;   // maior rpm_x10 alguma vez visto (glitch?)

static uint32_t g_last_net_pw_us   = 0u;
// Barometric correction: amostrar MAP quando motor parado por >300ms após key-on
static uint32_t g_baro_stopped_since_ms = 0u;
static bool     g_baro_sampled          = false;
static uint32_t g_loop2ms_last_us = 0u;
static uint32_t g_loop2ms_max_us = 0u;

static constexpr uint32_t kCalibSaveMinIntervalMs = 300000u;
static constexpr uint16_t kMapMinBarX100 = 10u;
static constexpr uint16_t kMapMaxBarX100 = 300u;
static constexpr uint16_t kLambdaMinMilli = 700u;
static constexpr uint16_t kLambdaMaxMilli = 1400u;

// =============================================================================
// Estado ETB e Torque Manager
// =============================================================================

static bool g_etb_initialized = false;

// =============================================================================
// Utilitários
// =============================================================================

static inline bool elapsed(uint32_t now, uint32_t last, uint32_t period) noexcept {
    return static_cast<uint32_t>(now - last) >= period;
}

static inline uint16_t build_status_bits(const ems::drv::CkpSnapshot& snap,
                                           const ems::drv::SensorData& sensors) noexcept {
    uint16_t status = 0u;
    if (snap.state == ems::drv::SyncState::FULL_SYNC) {
        status |= ems::app::STATUS_SYNC_FULL;
    }
    if (snap.phase_A) {
        status |= ems::app::STATUS_PHASE_A;
    }
    if (sensors.fault_bits != 0u) {
        status |= ems::app::STATUS_SENSOR_FAULT;
    }
    if (g_rev_limit_active) {
        status |= ems::app::STATUS_REV_LIMIT;
    }
    if (ems::engine::torque_manager_get_launch_active() != 0u) {
        status |= ems::app::STATUS_LAUNCH_ACTIVE;
    }
    if (ems::engine::torque_manager_get_tc_reduction() > 0u) {
        status |= ems::app::STATUS_TC_ACTIVE;
    }
    return status;
}

using ems::engine::clamp_u16;

static inline int8_t clamp_i8(int16_t v, int8_t lo, int8_t hi) noexcept {
    if (v < lo) { return lo; }
    if (v > hi) { return hi; }
    return static_cast<int8_t>(v);
}

// NVM map/corr loaders: app/nvm_boot.cpp (relocate-only hygiene PR-09).

static inline void comms_pump() noexcept {
    // Shuttle UART+USB↔protocolo a 2 ms. Ambos os transportes são servidos no
    // MESMO ritmo curto: o handshake de conexão do TunerStudio envia comandos
    // PLAIN (F, Q, ...) e, se a resposta demora, ele estoura o timeout curto e
    // envia o próximo comando antes de ler a resposta anterior — as duas
    // respostas saem então coladas ("001OpenEMS_v1.2") e o TS rejeita com
    // "Unsupported Controller Firmware". Servir o USB a 20 ms (como antes)
    // garantia esse gluing; a 2 ms cada comando é respondido a tempo, como nas
    // implementações de referência (Speeduino/rusEFI: request→resposta→flush
    // sub-ms). Nada aqui bloqueia (drena TX só com espaço no FIFO/rings).
    ems::hal::uart0_poll_rx(32u);
    {
        uint8_t b = 0u;
        while (ems::hal::uart0_rx_pop(b)) {
            ems::app::ui_rx_byte(b);
        }
    }
    ems::hal::usb_cdc_poll();
    if (ems::hal::usb_cdc_dtr()) {
        uint8_t rx_buf[64] = {};
        const uint16_t rx_n = ems::hal::usb_cdc_read_bytes(rx_buf, 64u);
        for (uint16_t i = 0u; i < rx_n; ++i) {
            ems::app::ui_rx_byte(rx_buf[i]);
        }
    }
    ems::app::ui_process();

    // Drena ui_tx → UART + USB (espelhado), limitado pelo MENOR espaço livre
    // entre os dois rings de destino — usb_cdc_send_bytes() descarta bytes
    // em silêncio se o seu próprio ring encher, então o orçamento tem de
    // respeitar ambos, não só o do UART, para nunca perder bytes de um frame.
    uint16_t budget = ems::hal::uart0_tx_free();
    const uint16_t usb_free = ems::hal::usb_cdc_tx_free();
    if (usb_free < budget) { budget = usb_free; }
    if (budget > 32u) { budget = 32u; }
    uint8_t tx_buf[32] = {};
    uint16_t tx_n = 0u;
    while (tx_n < budget && ems::app::ui_tx_pop(tx_buf[tx_n])) { ++tx_n; }
    if (tx_n != 0u) {
        for (uint16_t i = 0u; i < tx_n; ++i) {
            ems::hal::uart0_tx_push(tx_buf[i]);
        }
        ems::hal::usb_cdc_send_bytes(tx_buf, tx_n);
    }
    ems::hal::uart0_tx_poll_nb(16u);
}

// =============================================================================
// Inicialização — sequência idêntica ao main.cpp
// =============================================================================

static void openems_init() noexcept {
    // 1) PLL → 250 MHz + SysTick 1ms + IWDG 100ms
    system_stm32_init();

    // 1a) CRITICAL: INJ/IGN LOW before any delay.
    // PA15 resets as JTDI with pull-up → HIGH → injectors on (active-high).
    // PC10/11 float; external pull-ups can also pull INJ high.
    // Must run before the USB 300 ms wait (was: ECU_Hardware_Init after that).
    ::ecu_sched_outputs_safe_early();
    ::ecu_sched_set_inj_inhibit_mask(0x0Fu);
    ::ecu_sched_set_inj_pw_ticks(0u);

    // 1b) Reabilitar IRQs globais EXPLICITAMENTE. O Reset_Handler faz cpsid i e nunca
    // reabilita; antes isto só acontecia por efeito colateral do 1º cpsie de uma seção
    // crítica adiante, o que deixava a ISR do USB (e outras) mascaradas se a ordem mudasse.
    // Com SysTick já configurado em system_stm32_init(), é seguro habilitar aqui.
    __asm__ volatile("cpsie i" ::: "memory");

    // 1c) PB2 (LED WeAct) como saída — heartbeat visível desde o boot.
    GPIOB_MODER = (GPIOB_MODER & ~(3u << 4u)) | (1u << 4u);

    // 1d) USB CDC CEDO: só depende de clock (HSI48/CRS já prontos) + IRQs. Subir aqui,
    // antes dos inits da ECU (ADC/CAN/CKP), garante enumeração mesmo que algum init
    // adiante demore/bloqueie numa placa de bancada sem motor — a ISR cuida do resto.
    ems::hal::usb_cdc_init();

    // 1e) Janela p/ a enumeração USB (ISR-driven) completar antes dos inits da ECU, que
    // podem entrar em seção crítica (cpsid i) e mascarar a ISR do USB por um tempo.
    // ~300 ms kicando o IWDG (timeout 100 ms) a cada ~1 ms @ 250 MHz.
    // Re-assert INJ/IGN LOW each 100 ms in case USB/other init touches GPIOA.
    for (uint32_t ms = 0u; ms < 300u; ++ms) {
        for (volatile uint32_t d = 0u; d < 60000u; ++d) { /* ~1ms */ }
        iwdg_kick();
        ems::hal::usb_cdc_poll();
        if ((ms % 100u) == 0u) {
            GPIOB_ODR ^= (1u << 2u);
            ::ecu_sched_outputs_safe_early();
        }
    }

    // 2) Timers (TIM5=CKP IC)
    // misfire_init() DEVE preceder tim5_ic_init(): a tabela g_tooth_to_cyl parte de
    // BSS (zero), mas 0 é um índice de cilindro válido — o ISR do CKP leria cyl=0
    // para todos os dentes antes da tabela ser preenchida, gerando DTCs falsos.
    ems::engine::misfire_init();
    ems::hal::tim5_ic_init();   // → TIM5 input capture (CKP + CMP)
    iwdg_kick();

    // 2a) Scheduler unificado (re-asserts pin safe + clears event queue)
    ::ECU_Hardware_Init();
    ::ecu_sched_set_presync_inj_auto(1u);  // auto-select SIMULTANEOUS/SEMI_SEQUENTIAL by cranking
    ::ecu_sched_set_inj_inhibit_mask(0x0Fu);
    ::ecu_sched_set_inj_pw_ticks(0u);
    iwdg_kick();

    // 3) ADC (ADC1/ADC2 + TIM6 trigger)
    ems::hal::adc_init();
    iwdg_kick();

    // 4) CAN + bench communication. MVP transport: USART1 PA9/PA10.
    // (usb_cdc_init() já foi chamado cedo em 1b, antes dos inits da ECU.)
    ems::hal::can0_init();
    ems::hal::uart0_init(115200u);
    ems::hal::uart0_enable_rx();  // RX fica desligado por padrão (uart.cpp:61)
    ems::engine::ewg_control_init();
    ems::hal::flex_fuel_init();
    iwdg_kick();

	// 5) Flash Bank2 → carrega calibrações persistidas
	if (!ems::hal::nvm_load_calibration(0u, g_calib_page0, kCalibPageBytes)) {
		++g_flash_write_faults; // FIX: rastrear falha de leitura NVM
	}
	// Page 0 → globals through the protocol's own apply (one path for boot
	// and for a TunerStudio/dashboard write; timing light forced off).
	ems::app::ui_boot_apply_page0(g_calib_page0, kCalibPageBytes);
	// Gate de layout: páginas de tabela só carregam se a versão gravada no
	// page0 (byte 175) bater com o firmware — um blob de dimensão antiga
	// lido com o tamanho novo ganharia cauda 0xFF (VE=255!). Sem versão →
	// defaults de compilação; um "burn all" no dashboard re-persiste tudo.
	const bool cal_layout_ok =
		g_calib_page0[ems::engine::kCalLayoutVersionOffset] ==
		ems::engine::kCalLayoutVersion;
	ems::app::nvm_boot_load_tables(cal_layout_ok);
	if (!ems::hal::nvm_load_adaptive_maps()) {
		++g_flash_write_faults; // FIX: rastrear falha de leitura NVM
	}
    // 6) Drivers
    ems::drv::sensors_init();
    iwdg_kick();

    // 6a) Inicializa sistemas "invisíveis" ao motorista
    ems::engine::DiagnosticManager::init();
    ems::engine::map_estimator_init();
    ems::engine::xtau_autocalib_init();

    // 6b) Inicializa ETB e Torque Manager (borboleta eletrônica)
    g_etb_initialized = etb_control_init();
    // Auto-cal dos limites TPS a cada power-on (varre batentes no tick 2ms;
    // pulada se harness ausente; falha mantém a calibração de flash).
    if (g_etb_initialized) {
        ems::engine::etb_autocal_start();
    }
    torque_manager_init();
    iwdg_kick();

    // 7) Engine
    ems::engine::fuel_reset_adaptives();
    ems::engine::auxiliaries_init();
    ems::engine::knock_init();
    ems::engine::quick_crank_reset();
    iwdg_kick();

    // 8) Aplicação
    ems::app::ui_init();
    ems::app::can_stack_init(ems::engine::wbo2_can_id);

    // 9) NVIC — CKP fica com prioridade máxima. Injeção/ignição em TIM2/TIM1
    //    usam output compare direto por hardware, sem ISR no caminho crítico.
    //    SysTick configurado em system_stm32_init() com prio 11.
    nvic_set_priority(IRQ_TIM5, 1u);
    nvic_enable_irq(IRQ_TIM5);

    // 10) Aguardar CKP sync (timeout 5 s), heartbeat 5 Hz
    {
        const uint32_t sync_deadline = millis() + 5000u;
        uint32_t next_toggle = millis() + 100u;
        while (millis() < sync_deadline) {
            iwdg_kick();
            if (millis() >= next_toggle) {
                GPIOB_ODR ^= (1u << 2u);
                next_toggle = millis() + 100u;
            }
            const auto snap = ems::drv::ckp_snapshot();
            if (snap.state == ems::drv::SyncState::FULL_SYNC) { break; }
        }
    }

    // Kick final antes de entrar no main loop — garante que openems_init()
    // não ultrapassa o timeout de 100 ms do IWDG.
    iwdg_kick();
}


// =============================================================================
// main() — substituição do setup()/loop() do STM32 runtime
// =============================================================================

int main() {
    openems_init();

    uint32_t g_t2ms_   = millis();
    uint32_t g_t10ms_  = g_t2ms_;
    uint32_t g_t20ms_  = g_t2ms_;
    uint32_t g_t50ms_  = g_t2ms_;
    uint32_t g_t100ms_ = g_t2ms_;
    uint32_t g_t500ms_ = g_t2ms_;
    uint32_t g_t_etb_ms = g_t2ms_;
    uint32_t g_t_comms_ms = g_t2ms_;

    // Estreitar IWDG de 10s (boot) para 100ms (runtime): o main loop kica a cada
    // ciclo; 100ms detecta travamento de runtime sem tolerar os inits longos do boot.
    // Nota: IWDG_PR segue /256 (boot) → RLR=99 dá ~0.8s efetivo; suficiente p/ runtime
    // e evita esperar PVU/RVU de novo no caminho crítico.
    IWDG_KR  = IWDG_KR_ACCESS;
    IWDG_RLR = IWDG_RLR_100MS;
    IWDG_KR  = IWDG_KR_REFRESH;

    for (;;) {
        // ── Watchdog kick (primeiro statement) ───────────────────────────
        iwdg_kick();

        const uint32_t now = millis();

        // ── 2ms: fuel + ign recalc + commit calibration ───────────────────
        if (elapsed(now, g_t2ms_, 2u)) {
            g_t2ms_ = now;
            const uint32_t loop2ms_start_us = micros();

            // Stall watchdog: detecta virabrequim parado entre dentes.
            // Deve preceder ckp_snapshot() para que o snapshot deste ciclo
            // já reflicta LOSS_OF_SYNC se o motor parou.
            // Reactivado: os falsos stalls vinham do wrap 16-bit do TIM3;
            // desde a migração para TIM5 (32-bit) o elapsed é correcto.
            // Também decai rpm_x10 fantasma de ruído em CKP sem sync.
            ems::drv::ckp_stall_poll(ems::hal::tim5_count());

            // Dwell / injector open watchdogs (lost SPARK / lost INJ_OFF).
            ecu_sched_dwell_watchdog();
            ecu_sched_inj_watchdog();

            const auto snap    = ems::drv::ckp_snapshot();
            const auto sensors = ems::drv::sensors_get();

            // Teste de saídas em bancada: aborto imediato se RPM > 0 e
            // timeout de keepalive (o dwell watchdog acima continua activo).
            ems::engine::output_test_poll(now, snap.rpm_x10);
            ems::engine::EngineCalcIn calc_in{};
            calc_in.now_ms = now;
            calc_in.snap = snap;
            calc_in.sensors = sensors;
            calc_in.lambda_x1000 = ems::app::can_stack_lambda_milli();
            calc_in.lambda_valid = ems::app::can_stack_wbo2_fresh(now);
            calc_in.torque_spark_retard_deg = g_torque_spark_retard_deg;
            const ems::engine::EngineCalcOut& calc = ems::engine::engine_calc_step(calc_in);
            ems::app::ui_set_rev_limit_active(g_rev_limit_active);
            ems::app::ui_update_rt_map_fuel(calc.map_fused_x100, calc.net_pw_us);
            g_last_map_fused_x100 = calc.map_fused_x100;
            g_last_net_pw_us = calc.net_pw_us;
            g_last_pw_ms_x10 = calc.pw_ms_x10;
            g_limp_active = calc.limp_active;
            g_dbg_rev_limit_rpm_max = calc.rpm_max_x10;
            if (calc.committed) {
                // Telemetry keeps whole degrees (rounded); the scheduler got 0.1°.
                const int16_t x10 = calc.spark_x10;
                g_last_advance_x10 = x10;
                g_last_advance_deg = clamp_i8(
                    static_cast<int16_t>((x10 + (x10 >= 0 ? 5 : -5)) / 10), -20, 60);
            }

            // EWG position inner loop (2ms cadence)
            if (!ems::engine::output_test_active()) {
                const uint16_t demand = ems::engine::auxiliaries_ewg_position_demand_x10();
                const uint16_t pos = ems::engine::ewg_read_position_pct_x10();
                ems::engine::ewg_control_update(demand, pos);
            }

            g_loop2ms_last_us = micros() - loop2ms_start_us;
            if (g_loop2ms_last_us > g_loop2ms_max_us) {
                g_loop2ms_max_us = g_loop2ms_last_us;
            }
            ems::app::ui_update_loop_diag(g_loop2ms_last_us, g_loop2ms_max_us);
        }

        // ── 10ms: VVT, wastegate PID ─────────────────────────────────────
        if (elapsed(now, g_t10ms_, 10u)) {
            g_t10ms_ = now;
            ems::engine::auxiliaries_tick_10ms();
        }

        // ── 20ms: UI proprietaria + aux tasks ───────────────────────────
        if (elapsed(now, g_t20ms_, 20u)) {
            g_t20ms_ = now;
            const auto snap = ems::drv::ckp_snapshot();
            const auto sensors = ems::drv::sensors_get();
            ems::app::ui_update_rt_metrics(g_last_pw_ms_x10, g_last_advance_deg, g_last_stft_pct,
                                           g_last_lambda_target_d4, g_last_ltft_pct);
            ems::app::ui_update_rt_sched_diag(
                g_late_event_count,
                g_cycle_schedule_drop_count,
                g_calibration_clamp_count,
                g_last_advance_x10,
                static_cast<uint8_t>(snap.state));
            // Transporte (UART+USB RX/TX/parse) vive em comms_pump() a 2 ms.
            ems::engine::auxiliaries_tick_20ms();
            ems::app::can_stack_process(now, snap, sensors,
                                        g_last_advance_deg,
                                        g_last_pw_ms_x10,
                                        g_last_stft_pct,
                                        0u, 0u,
                                        build_status_bits(snap, sensors));
        }

        // ── 50ms: sensores lentos ──────────────────────────────────────────
        if (elapsed(now, g_t50ms_, 50u)) {
            g_t50ms_ = now;
            ems::drv::sensors_tick_50ms();
        }

        // ── 100ms: sensores + STFT + misfire report + baro ──────────────
        if (elapsed(now, g_t100ms_, 100u)) {
            g_t100ms_ = now;
            ems::drv::sensors_tick_100ms();

            // Knock sensor morto (FOME #578): report único na transição.
            {
                static bool s_knock_dead_reported = false;
                const bool dead = ems::engine::knock_sensor_dead();
                if (dead && !s_knock_dead_reported) {
                    ems::engine::DiagnosticManager::report_fault(
                        ems::engine::DiagnosticCode::KNOCK_SENSOR_FAULT,
                        ems::engine::FaultSeverity::WARNING);
                    s_knock_dead_reported = true;
                } else if (!dead) {
                    s_knock_dead_reported = false;
                }
            }

            // Flex fuel: stoich AFR from ethanol % (E0 = 14.7, E100 = 9.0,
            // linear) as a runtime override — the configured stoich (page 0)
            // is never overwritten, so it cannot be burned to flash.
            ems::engine::fuel_set_stoich_override_x100(
                ems::hal::flex_fuel_valid()
                    ? static_cast<uint16_t>(1470u - (ems::hal::flex_fuel_ethanol_pct() * 570u) / 100u)
                    : 0u);
            const auto snap    = ems::drv::ckp_snapshot();
            const auto sensors = ems::drv::sensors_get();
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

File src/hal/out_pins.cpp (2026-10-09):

/**
 * @file hal/out_pins.cpp
 * INJ/IGN GPIO init + safe de-assert (relocated from ecu_sched_outputs_safe_early).
 */
#include "hal/out_pins.h"

#if defined(EMS_HOST_TEST)

namespace ems::hal::out_pins_host {
uint32_t rcc_ahb2enr1 = 0u;
uint32_t gpioa_moder = 0u, gpiob_moder = 0u, gpioc_moder = 0u, gpioe_moder = 0u;
uint32_t gpioa_otyper = 0u, gpiob_otyper = 0u, gpioc_otyper = 0u, gpioe_otyper = 0u;
uint32_t gpioa_pupdr = 0u, gpiob_pupdr = 0u, gpioc_pupdr = 0u, gpioe_pupdr = 0u;
uint32_t gpioa_afrh = 0u;
uint32_t gpioa_bsrr = 0u, gpiob_bsrr = 0u, gpioc_bsrr = 0u, gpioe_bsrr = 0u;
void (*write_hook)(uint8_t, uint8_t) = nullptr;
}  // namespace ems::hal::out_pins_host

#else
#include "hal/regs.h"
#endif

namespace ems::hal {

void out_pins_hw_init() noexcept {
    for (volatile uint32_t d = 0u; d < 8u; ++d) {}

#if EMS_BOARD_IS_VGT6
    // VGT6: all INJ/IGN on GPIOE — push-pull LOW (active-high actuators).
    RCC_AHB2ENR1 |= RCC_AHB2ENR1_GPIOEEN;
    for (volatile uint32_t d = 0u; d < 8u; ++d) {}
    // 8 canais INJ/IGN: push-pull, sem pull, LOW = desligado.
    static const uint8_t pe_pins[] = {0U, 2U, 4U, 6U, 9U, 11U, 13U, 15U};
    for (uint8_t i = 0U; i < (sizeof(pe_pins) / sizeof(pe_pins[0])); ++i) {
        const uint8_t pin = pe_pins[i];
        GPIOE_OTYPER &= ~(1U << pin);
        GPIOE_PUPDR  = (GPIOE_PUPDR & ~(3U << (pin * 2U)));
        GPIOE_MODER  = (GPIOE_MODER & ~(3U << (pin * 2U))) | (1U << (pin * 2U));
    }
    // Escrita ÚNICA e atómica: tudo ao estado seguro de uma vez. Não separar em
    // duas escritas — além de deixar uma janela entre elas, o mock de host só
    // regista a última e o teste de cobertura VGT6 deixaria de ver os canais.
    GPIOE_BSRR = (1U << (0U + 16U)) | (1U << (2U + 16U)) | (1U << (4U + 16U))
               | (1U << (6U + 16U)) | (1U << (9U + 16U)) | (1U << (11U + 16U))
               | (1U << (13U + 16U)) | (1U << (15U + 16U));
#else
    // RGT6: INJ PA15/PB3/PC10/PC11 · IGN PC6–9
    // PA15 after reset is often JTDI with pull-up → HIGH until here.
    RCC_AHB2ENR1 |= RCC_AHB2ENR1_GPIOAEN | RCC_AHB2ENR1_GPIOBEN | RCC_AHB2ENR1_GPIOCEN;
    for (volatile uint32_t d = 0u; d < 8u; ++d) {}

    GPIOA_AFRH = (GPIOA_AFRH & ~(0xFu << ((15U - 8U) * 4U)));
    GPIOA_OTYPER &= ~(1U << 15U);
    GPIOA_PUPDR  = (GPIOA_PUPDR & ~(3U << (15U * 2U)));
    GPIOB_OTYPER &= ~(1U << 3U);
    GPIOB_PUPDR  = (GPIOB_PUPDR & ~(3U << (3U * 2U)));
    for (uint8_t pin = 6U; pin <= 11U; ++pin) {
        GPIOC_OTYPER &= ~(1U << pin);
        GPIOC_PUPDR  = (GPIOC_PUPDR & ~(3U << (pin * 2U)));
    }

    GPIOA_MODER = (GPIOA_MODER & ~(3U << (15U * 2U))) | (1U << (15U * 2U));
    GPIOB_MODER = (GPIOB_MODER & ~(3U << (3U * 2U))) | (1U << (3U * 2U));
    for (uint8_t pin = 6U; pin <= 11U; ++pin) {
        GPIOC_MODER = (GPIOC_MODER & ~(3U << (pin * 2U))) | (1U << (pin * 2U));
    }

    GPIOA_BSRR = (1U << (15U + 16U));
    GPIOB_BSRR = (1U << (3U + 16U));
    GPIOC_BSRR = (1U << (6U + 16U)) | (1U << (7U + 16U))
               | (1U << (8U + 16U)) | (1U << (9U + 16U))
               | (1U << (10U + 16U)) | (1U << (11U + 16U));
#endif
}

#if defined(EMS_HOST_TEST)
uint32_t out_pins_test_bsrr_snapshot(uint8_t port) noexcept {
    using namespace out_pins_host;
    switch (port) {
    case 0: return gpioa_bsrr;
    case 1: return gpiob_bsrr;
    case 2: return gpioc_bsrr;
    case 3: return gpioe_bsrr;
    default: return 0u;
    }
}

void out_pins_test_reset_stubs() noexcept {
    using namespace out_pins_host;
    rcc_ahb2enr1 = 0u;
    gpioa_moder = gpiob_moder = gpioc_moder = gpioe_moder = 0u;
    gpioa_otyper = gpiob_otyper = gpioc_otyper = gpioe_otyper = 0u;
    gpioa_pupdr = gpiob_pupdr = gpioc_pupdr = gpioe_pupdr = 0u;
    gpioa_afrh = 0u;
    gpioa_bsrr = gpiob_bsrr = gpioc_bsrr = gpioe_bsrr = 0u;
}
#endif

}  // namespace ems::hal

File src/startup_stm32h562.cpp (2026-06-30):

#include <cstdint>

extern "C" int main();
extern "C" void __libc_init_array();

extern "C" uint32_t _estack;
extern "C" uint32_t _sidata;
extern "C" uint32_t _sdata;
extern "C" uint32_t _edata;
extern "C" uint32_t _sbss;
extern "C" uint32_t _ebss;

extern "C" void Default_Handler();
extern "C" [[noreturn]] void Reset_Handler();
extern "C" void SysTick_Handler()            noexcept __attribute__((weak, alias("Default_Handler")));
extern "C" void ADC1_IRQHandler()            noexcept __attribute__((weak, alias("Default_Handler")));
extern "C" void ADC2_IRQHandler()            noexcept __attribute__((weak, alias("Default_Handler")));
extern "C" void GPDMA1_Channel0_IRQHandler() noexcept __attribute__((weak, alias("Default_Handler")));
extern "C" void GPDMA1_Channel1_IRQHandler() noexcept __attribute__((weak, alias("Default_Handler")));
extern "C" void TIM1_CC_IRQHandler()         noexcept __attribute__((weak, alias("Default_Handler")));
extern "C" void TIM2_IRQHandler()            noexcept __attribute__((weak, alias("Default_Handler")));
extern "C" void TIM3_IRQHandler()            noexcept __attribute__((weak, alias("Default_Handler")));
extern "C" void TIM5_IRQHandler()            noexcept __attribute__((weak, alias("Default_Handler")));
extern "C" void USB_IRQHandler()             noexcept __attribute__((weak, alias("Default_Handler")));
extern "C" void EXTI5_9_IRQHandler()        noexcept __attribute__((weak, alias("Default_Handler")));

extern "C" void _init() {}
extern "C" void _fini() {}

/* FIX ERRATA FLASH: Handlers críticos marcados com .fastrun para execução em SRAM */
extern "C" void Default_Handler() __attribute__((section(".fastrun")));
extern "C" [[noreturn]] void Reset_Handler() __attribute__((section(".fastrun")));

extern "C" void Default_Handler() {
    // Trigger SYSRESETREQ so an unhandled IRQ resets the MCU instead of hanging.
    *reinterpret_cast<volatile uint32_t*>(0xE000ED0Cu) = 0x05FA0004u;
    while (true) { }
}

extern "C" [[noreturn]] void Reset_Handler() {
    /* 1. Desactivar IRQs e corrigir VTOR — DFU jump pode deixar VTOR errado */
    __asm__ volatile ("cpsid i");
    *reinterpret_cast<volatile uint32_t*>(0xE000ED08u) = 0x08000000u;  // VTOR = Flash

    /* 2. Kick WWDG imediatamente (hardware WWDG activo desde reset) */
    *reinterpret_cast<volatile uint32_t*>(0x40002C00u) = 0x7Fu;  // WWDG_CR refresh

    /* 3. Forcar SYSCLK = HSI16
     * OBRIGATORIO: activar HSI16 primeiro (DFU pode ter desligado para usar PLL/HSE)
     * RCC_CR @ 0x44020C00: HSION=bit0, HSIRDY=bit1
     * RCC_CFGR1 @ 0x44020C1C: SW[1:0]=bits[1:0], SWS[1:0]=bits[4:3] */
    {
        volatile uint32_t* rcc_cr  = reinterpret_cast<volatile uint32_t*>(0x44020C00u);
        volatile uint32_t* cfgr1   = reinterpret_cast<volatile uint32_t*>(0x44020C1Cu);

        // 3a. Ligar HSI16 e aguardar pronto
        *rcc_cr |= (1u << 0u);  // HSION = 1
        for (volatile uint32_t t = 20000u; t > 0u; --t) {
            if (*rcc_cr & (1u << 1u)) break;  // aguardar HSIRDY
        }

        // 3b. Mudar SYSCLK para HSI16 e aguardar
        *cfgr1 = (*cfgr1 & ~0x3u);              // SW[1:0] = 00 (HSI16)
        for (volatile uint32_t t = 10000u; t > 0u; --t) {
            if ((*cfgr1 & (3u << 3)) == 0u) break; // aguardar SWS=00
        }
        // Desligar PLL1 (liberta energia, confirma HSI16 exclusivo)
        // NAO alterar Flash latency aqui: VOS3 (default reset) exige >=1WS a 16MHz
        *reinterpret_cast<volatile uint32_t*>(0x44020C00u) &= ~(1u << 24u); // PLL1ON=0

        // Reset prescalers AHB/APB1/APB2 para 1 (DFU pode ter configurado divisores)
        // CFGR2 @ 0x44020C20: HPRE[3:0]=0, PPRE1[6:4]=0, PPRE2[10:8]=0 -> todos /1
        volatile uint32_t* cfgr2 = reinterpret_cast<volatile uint32_t*>(0x44020C20u);
        *cfgr2 &= ~0x77Fu;  // limpar HPRE+PPRE1+PPRE2

        // USART1 clock = HSI16 directamente (independente de prescalers)
        // CCIPR1 @ 0x44020CD8: USART1SEL[2:0] = 011 = HSI16
        volatile uint32_t* ccipr1 = reinterpret_cast<volatile uint32_t*>(0x44020CD8u);
        *ccipr1 = (*ccipr1 & ~0x7u) | 0x3u;
    }

    /* 3. Copia .data para RAM */
    const uint32_t* src = &_sidata;
    for (uint32_t* d = &_sdata; d < &_edata; ++d, ++src) {
        *d = *src;
    }
    /* Zera .bss */
    for (uint32_t* d = &_sbss; d < &_ebss; ++d) {
        *d = 0u;
    }
    __libc_init_array();
    static_cast<void>(main());
    while (true) { }
}

using Handler = void (*)();

extern "C" __attribute__((section(".isr_vector"), used))
Handler const g_vector_table[] = {
    reinterpret_cast<Handler>(&_estack),
    Reset_Handler,
    Default_Handler,
    Default_Handler,
    Default_Handler,
    Default_Handler,
    Default_Handler,
    nullptr, nullptr, nullptr, nullptr,
    Default_Handler,
    Default_Handler,
    nullptr,
    Default_Handler,
    SysTick_Handler,
    // IRQ0..IRQ15
    Default_Handler, Default_Handler, Default_Handler, Default_Handler,
    Default_Handler, Default_Handler, Default_Handler, Default_Handler,
    Default_Handler, Default_Handler, Default_Handler, Default_Handler,
    Default_Handler, Default_Handler, Default_Handler, Default_Handler,
    // IRQ16..IRQ31
    Default_Handler, Default_Handler, Default_Handler, Default_Handler,
    Default_Handler, Default_Handler, Default_Handler, EXTI5_9_IRQHandler, // IRQ23=EXTI[9:5]
    Default_Handler, Default_Handler, Default_Handler, GPDMA1_Channel0_IRQHandler,
    GPDMA1_Channel1_IRQHandler, Default_Handler, Default_Handler, Default_Handler,
    // IRQ32..IRQ47
    Default_Handler, Default_Handler, Default_Handler, Default_Handler,
    Default_Handler, ADC1_IRQHandler, Default_Handler, Default_Handler,
    Default_Handler, Default_Handler, Default_Handler, Default_Handler,
    TIM1_CC_IRQHandler, TIM2_IRQHandler, TIM3_IRQHandler, Default_Handler, // IRQ44=TIM1_CC, 45=TIM2, 46=TIM3, 47=TIM4
    // IRQ48..IRQ63
    TIM5_IRQHandler, Default_Handler, Default_Handler, Default_Handler,
    Default_Handler, Default_Handler, Default_Handler, Default_Handler,
    Default_Handler, Default_Handler, Default_Handler, Default_Handler,
    Default_Handler, Default_Handler, Default_Handler, Default_Handler,
    // IRQ64..IRQ69  (64=LPTIM1, 65=TIM8_BRK, 66=TIM8_UP, 67=TIM8_TRG, 68=TIM8_CC, 69=ADC2)
    Default_Handler, Default_Handler, Default_Handler, Default_Handler,
    Default_Handler, ADC2_IRQHandler,
    // IRQ70..IRQ74  (73=TIM17, 74=USB DRD FS)
    // USB_DRD_FS_IRQn=74 confirmed from stm32h562xx.h
    Default_Handler, Default_Handler, Default_Handler, Default_Handler, USB_IRQHandler,
};

static_assert((sizeof(g_vector_table) / sizeof(g_vector_table[0])) >= (16u + 74u + 1u),
              "STM32H562 vector table must include USB IRQ74");

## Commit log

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2026-02-28 fix: corrigir build quebrado após remoção de o2_mv e adição de AN1-4
    A sequência delete+restore entre commits deixou sensors.h incompleto
    (faltavam SensorId, SensorRange, campos an1-4, declarações de funções)
    e vários arquivos referenciando SensorData.o2_mv que havia sido removido.
    Correções aplicadas:
    - src/drv/sensors.h: adiciona SensorId, SensorRange, an1_raw-an4_raw e
    todas as declarações de funções públicas (era apenas stub da struct)
    - src/drv/sensors.cpp: remove atribuição g_data.o2_mv (campo inexistente);
    g_o2_filt mantido apenas para fault tracking
    - src/app/tuner_studio.cpp: inclui can_stack.h e usa can_stack_lambda_milli()
    no lugar de s.o2_mv para preenc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
    [sensors.cpp, sensors.h]
2026-02-28 engine/scheduler/main: fix 8 peer-review bugs
    Fix 1 (fuel_calc): calc_base_pw_us denominator 255→100.
    VE table stores direct percentages; denominator 100 ensures
    VE=100 + MAP=MAP_ref → pw = req_fuel_us exactly.
    Updated test expectations accordingly.
    Fix 2 (scheduler): sched_isr uses circular uint16 arithmetic.
    Previous linear (ev > now) break fails on FTM0 wrap-around (~1 ms).
    Replaced with dist-based check; changed break→continue so all
    queue entries are evaluated independently.
    Fix 3 (main): CAN 0x400 now carries real advance and PW values.
    Added g_last_advance_deg / g_last_pw_ms_x10 statics computed
    each 5 ms task; added kDefaultReqFuelUs / kMapRefKpa constants.
    F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
    [sensors.cpp]
2026-03-01 fix: apply all P1–P9 EMS logic corrections (all tests green)
    P9 — table3d/ign_calc: lerp retorna exatamente b quando frac_q8==255
    P5 — CAN 500 kbps: PROPSEG 6→5 para TotalTq=20 (2 µs/bit exacto)
    P8 — sensors: remove g_mafv_filt e caminho de tensão MAF; mantém
    fault detection e estimativa por frequência (FTM3 CH1)
    P1 — tuner_studio: páginas 1/2 sincronizadas bidireccionalmente com
    ve_table e spark_table em leitura e escrita; init a partir das tabelas
    P2 — tuner_studio: pw1_ms_x10, advance_p40 e stft_p100 populados via
    ts_update_rt_metrics() chamado no slot de 5 ms de main.cpp
    P3 — knock: persiste knock_retard_x10[cyl] e vosel no FlexNVM via
    knock_save_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
    [ign_calc.cpp, knock.cpp, sensors.cpp]
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2026-03-02 drv/engine/hal: implement Engine Position and Scheduling Core (60-2 wheel)
    Module 1 — DECODE (ckp.cpp / ckp_ftm3_ch0_isr):
    - Upgrade wheel from 36-1 to 60-2 (58 real teeth, 6° per tooth)
    - Timestamp read from FTM3_C0V (hardware capture) not FTM3_CNT,
    preventing ISR-latency jitter (RusEFI #1488 pattern)
    - Circular uint16_t delta arithmetic handles counter overflow correctly
    - Dynamic ±20% tolerance window rejects EMC noise without false gaps
    - Ratio-based gap detection (period × 2 > avg × 3 ≡ period > 1.5×avg)
    is robust against RPM changes; 60-2 gap ≈ 3× normal (100% margin)
    Module 2 — SYNC (state machine in ckp.cpp):
    - Replace 3-state {WAIT, SYNCING, SYNCED} with 4-state m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
    [auxiliaries.cpp, ckp.cpp]
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2026-03-07 fix: corrige 13 issues de decode/sync/scheduling (revisão código mar/2026)
    CRÍTICOS
    --------
    CKP-01: documenta invariante de prioridade FTM3 CH0/CH1 (mesma IRQ,
    naturalmente não-reentrantes). Adiciona static_assert(IRQ_FTM3==71)
    em hal/ftm.cpp para detectar renumeração acidental.
    CKP-02: process_gap_event() agora exige tooth_count >= kGapThresholdTooth
    em WAIT_GAP e LOSS_OF_SYNC. Gap durante bootstrap (< 3 amostras de
    histórico) não avança mais o estado. Bloco externo simplificado.
    ATENÇÃO
    -------
    CKP-03: parâmetro angle_x10 → angle_mdeg em ckp_angle_to_ticks()
    (semântica era miligraus, nome dizia ×10 — fonte garantida de erro).
    CK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
    [ckp.cpp, ecu_sched.cpp, ign_calc.cpp]
2026-03-08 fix: fecha 5 lacunas pós-refatoração (GAP-1 a GAP-5)
    GAP-1 (ckp_angle_to_ticks sem caller): documenta domínio de clock FTM3
    vs FTM0 e status reservado no Doxygen de ckp.h; adiciona comentário RESERVADA
    no corpo da função em ckp.cpp. Nenhuma mudança de comportamento.
    GAP-2 (g_calibration_clamp_count nunca zerado em produção): adiciona
    ecu_sched_reset_diagnostic_counters() que zera 7 contadores de diagnóstico
    via seção crítica. Chamado em main.cpp dentro do bloco de stop de motor
    (após 100 ms de rpm=0 confirmado), exatamente uma vez por parada — os
    contadores passam a refletir o período de marcha mais recente em vez de
    acumular como odômetro lifetime.
    GAP-3 (artifacts em v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
    [ckp.cpp, ecu_sched.cpp, ecu_sched.h]
2026-03-08 hardening: fix nested CPSID, add FASTRUN to CKP ISRs, guard DMB/volatile
    Grupo E — latency/jitter fixes (completing full hardening plan):
    FIX-7 (nested CPSID bug): change current_timestamp32() to use PRIMASK
    save/restore (mrs/msr) instead of plain CPSID/CPSIE. When called from
    within Add_Event()'s outer critical section, the inner exit no longer
    re-enables IRQs — restores PRIMASK to its saved value (still disabled).
    Eliminates the race window where FTM0 ISR could preempt mid-insertion.
    FIX-11 (DMB host guard): wrap __asm__ volatile("dmb") in
    #if defined(__arm__) || defined(__thumb__) in force_output() and
    arm_channel() — x86_64 host tests cannot assemble ARM DMB instruction.
    FIX-15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
    [auxiliaries.cpp, ckp.cpp, ecu_sched.cpp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]
2026-03-08 drv/ckp, engine: corrigir divisor 58→60 em cálculos angulares (roda 60-2)
    Roda 60-2 tem 60 posições angulares uniformes de 6° cada. Os 2 dentes
    ausentes (gap) não alteram o espaçamento dos demais. Código usava 58
    (nº de dentes físicos) em cálculos angulares, causando erro de ~3,45%:
    - ckp.cpp rpm_x10_from_period_ns(): / 58 → / 60 (adiciona kTeethPositionsPerRev=60)
    - cycle_sched.cpp sub_teeth(): (teeth×360)/58 → /60
    - cycle_sched.cpp angle_to_tp(): (local×58)/360 → ×60
    - auxiliaries.cpp calc_cam_pos_est_x10(): constante 6207 (≈36000/58) → ×60 (=6,0°×10)
    - ecu_sched.cpp near_time_window_ticks(): tpr/58 → tpr/60
    - test_ckp.cpp: period_ns 1293103 → 1250000 (corr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
    [auxiliaries.cpp, ckp.cpp, ecu_sched.cpp]
2026-03-08 engine/sched: migrate to angle-domain scheduling (v3)
    Replaces time-domain timestamp queue with angular event table
    (tooth_index, sub_frac_x256, phase_A), eliminating three critical issues:
    1. Silent race condition: g_overflow_count read by FTM3 ISR (prio 1)
    before FTM0 ISR (prio 4) could increment it after overflow — timestamp
    up to 4.37 ms stale. Fixed by removing g_overflow_count entirely.
    2. O(32) overhead in CKP ISR: retime_far_events_from_tooth_rpm() traversed
    the full queue 58×/revolution at highest ISR priority. Replaced by a
    simple O(20) loop over a static angle table.
    3. RPM-change timing error: events scheduled with ticks_per_rev from gap
    moment; retimestampin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
    [ecu_sched.cpp, ecu_sched.h]
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2026-03-09 engine: corrige clamp de avanço, implementa prime pulse e atualiza spec.md
    Ponto 1 (spec): fórmula O2 corrigida para 5V (raw×5000/4095).
    Ponto 2 (spec): REQ_FUEL documentado com fórmula completa e referência E30.
    Ponto 3 (spec): EOI/IVC documentado como limitação conhecida (sem IVC implementado).
    Ponto 4 (código+spec): clamp_advance_deg expandido de 35° para 40° BTDC.
    Ponto 5 (código+spec): prime pulse — injeção simultânea no 5º dente CKP,
    sem requisito de sincronização, PW = REQ_FUEL × kCrankFuelMult(CLT),
    máximo 30 000 µs. Implementado via hook prime_on_tooth (ISR) + flag ISR-safe
    + ecu_sched_fire_prime_pulse (FTM0 CH0-3 ON/OFF via IRQ re-arm).
    5 novos testes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
    [ckp.cpp, ecu_sched.cpp, ecu_sched.h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]
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2026-03-14 feat: add standalone OpenEMS-STM32H562 port as openems-stm32h5/
    Creates a complete standalone firmware repository targeting the
    STM32H562RGT6 (Cortex-M33 @ 250 MHz), adapted from the Teensy 3.5
    codebase. All 15+ host test suites pass with zero failures.
    Key differences from the Kinetis/Teensyduino version:
    - HAL rewritten for STM32H562: ADC, CAN (FDCAN1), UART, Timers, Flash
    - PLL 250 MHz via system_stm32_init() + SysTick millis
    - Flash Bank2 EEPROM emulation replaces FlexNVM (LTFT, knock, calibration)
    - IWDG 100 ms watchdog replaces PIT1
    - TIM5 input-capture for CKP, TIM1 output-compare for injection/ignition
    - Bare-metal entry point (no Arduino/Teensyduino dependency)
    - Fixed nvm_test_set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
    [auxiliaries.cpp, ckp.cpp, ecu_sched.cpp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]
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2026-04-23 refactor: remove legacy v1.1/v2.2, implement engine safety guards
    DELETIONS (Legacy Code Removal):
    - Delete src/ (v1.1 Teensy implementation, 47 files)
    - Delete openems-stm32h5/ (v2.2 STM32H5 port, 61 files)
    - Delete test/ (v1.1 legacy test suites, 18 files)
    - Delete docs/*.docx (binary file)
    Rationale:
    - v3 is now the sole active version
    - v1.1/v2.2 served as reference for 79% code reuse
    - Repository size reduced ~1.7 MB (15%)
    - All functionality migrated to openems-v3/
    SAFETY IMPROVEMENTS (Audit-Driven):
    1. AE (Acceleration Enrichment) Overflow Guard
    File: openems-v3/src/engine/fuel_calc.cpp
    Change: Skip AE calculation if dt_ms < 5 ms
    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
    [auxiliaries.cpp, ckp.cpp, ecu_sched.cpp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]
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2026-05-05 Correções críticas no firmware OpenEMS - DMA, ISRs, seções críticas e tratamento de falhas
    - Corrigido GPDMA Channel1 chamando função errada em ISR
    - Implementado snapshot atômico com memcpy + seção crítica
    - Corrigido race condition em arm_channel com enter_critical/exit_critical
    - Adicionado tratamento de falhas para busy-wait em adc_wait_ready
    - Corrigido variáveis não voláteis acessadas em contexto ISR
    - Adicionado verificação de retorno em funções de gravação NVM
    - Corrigido variáveis de calibração sem verificação adequada
    - Atualizadas seções críticas em acesso a registradores de hardware
    - Corrigido leitura de GPIO pós-capture (abordagem limitada)
    - Adici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
    [ckp.cpp, ecu_sched.cpp]
2026-05-05 fix: corrige race conditions, DMA, volatile e retornos de erro
    - Corrige uso incorreto de volatile em struct compartilhada (memcpy + critical section)
    - Fix: gpdma_adc1_arm() -> gpdma_adc2_arm() no ISR do Channel1 (ADC2)
    - adc_wait_ready(): adiciona retorno bool + contador de falha + recovery
    - Protege arm_channel() com critical section entre scheduler_counter() e *ccr write
    - Flash/NVM: adiciona verificacao de retornos e contadores de falha
    - Remove TunerStudio, adiciona UI protocol proprio
    - Tabelas 3D com verificacao de limites e protecao contra corrupcao
    - math_utils com saturacao e clamp seguros
    - Fuel transient compensation
    - Reorganiza ecu_sched, quick_crank, ign_calc com critical sec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
    [auxiliaries.cpp, calibration.cpp, ecu_sched.cpp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]
2026-05-06 fix: restaura ecu_sched.cpp corrompido no commit anterior + reordena SR clear
    O commit 7a325ef introduziu ecu_sched.cpp com numeros de linha prefixados
    (NNN|) e truncado na linha 498 (faltava } e todas as funcoes setter/test).
    Restaura a versao funcional de 50f75ed e aplica a unica mudanca real:
    - Clear SR flag ANTES de programar CCR em arm_channel() para evitar
    perder edges do output compare quando o flag e setado pelo hardware
    entre o DMB e a escrita do CCR.
    [ecu_sched.cpp]
2026-05-06 fix: correções críticas do ADC/DMA e tratamento de falhas NVM
    ADC/DMA (adc.cpp):
    - CRÍTICA: Removido GPDMA_CCR_CIRC + ADC_CFGR1_DMACFG — conflito
    arquitetural com re-arm manual no ISR. Modo circular faz DMA reiniciar
    sozinho, mas o ISR faz RESET+re-init criando janela de perda de dados.
    Agora opera em one-shot com re-arm no ISR (padrão seguro para ECU).
    - ALTA: Adicionado timeout em adc_prepare_for_config() while(ADC_CR_ADCAL)
    — sem isso, firmware congela se calibração não completar.
    - ALTA: Corrigida sequência de recovery em adc_enable() — DEEPPWD=1 com
    ADEN=1 viola RM0481 §25.4.2. Ordem correta: ADEN=0 → DEEPPWD=1 →
    DEEPPWD=0 → ADVREGEN=1 → ADEN=1.
    - MÉ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
    [main_stm32.cpp]
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2026-05-06 fix: sanitize hardening — divisão por zero, bounds, flash timeout
    - timer.cpp: guarda freq_hz==0 em tim3/tim4_pwm_init (divisão por zero);
    clamp duty_pct_x10 ≤ 1000 em tim3/tim4_set_duty
    - can.cpp: check defensivo get_idx < 3 antes de indexar FIFO Message RAM
    - flash.cpp: flash_wait_ready() com timeout (≤300k iters) + fault counter
    g_flash_wait_timeouts; elimina busy-wait infinito se hardware falhar
    - sensors.cpp: apply_fault valida idx < 8 antes de g_fault[] e bit < 8
    antes de shift — protege contra expansão futura do enum SensorId
    - ui_protocol.cpp: handle_read_done verifica ptr != nullptr antes de
    tx_push_bytes; responde kAckErr se page_ptr retornar nullptr
    https://cla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
    [sensors.cpp]
2026-05-06 feat: FASE 3 engine config runtime + USB register defs (FASE 2 partial)
    - engine_config.h: add EngineConfigRam struct with runtime-configurable
    parameters (displacement_cc, injector_flow_cc_min, stoich_afr_x100,
    map_ref_kpa, trigger_tooth0_engine_deg, default_soi_lead_deg)
    - engine_config.cpp: implement load/apply/serialize/validate with magic
    0x4543 at page0 offset 14; falls back to compile-time defaults if magic
    missing or values out of range
    - fuel_calc.cpp: default_req_fuel_us() and calc_base_pw_us_default() now
    read from g_eng_cfg at runtime instead of compile-time kDefaultReqFuelUs
    - main_stm32.cpp: call engine_config_load() at boot after NVM load;
    call engine_config_serial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
    [main_stm32.cpp]
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2026-05-15 Title: Implement Remaining Recommendations from Improvement Plan
    Key features implemented:
    - Created IMPROVEMENTS.md with detailed P0-P3 priority issues and fixes
    - Added engine/constants.h with centralized timing, physical, and flash constants
    - Implemented hal/critical_section.h with RAII wrapper for interrupt management
    - Developed comprehensive diagnostic manager with fault codes and plausibility checks
    - Enhanced sensor plausibility validation between MAP, TPS, and RPM values
    - Updated Makefile to include diagnostic manager in build system
    - Fixed TIM8 16-bit overflow in ignition scheduling with proper wrap handling
    - Added flash write protection during engine operation above safe RPM t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
    [ckp.cpp, ecu_sched.cpp, main_stm32.cpp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]
2026-05-15 Implement ADC recovery system and sensor fault handling
    - Added comprehensive ADC recovery mechanism in src/hal/adc.cpp with timeout detection, deep power-down sequence, and retry logic to handle runtime ADC failures
    - Integrated ADC recovery status checks into sensor sampling routines in src/drv/sensors.cpp to switch to safe default values during recovery
    - Enhanced sensor fault detection and diagnostic reporting with fallback values for critical sensors (MAP, TPS, CLT, IAT) when ADC is unavailable
    - Extended diagnostic manager integration to report ADC recovery events and sensor range faults with appropriate severity levels
    - Updated ADC HAL interface in src/hal/adc.h to expose recovery st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
    [sensors.cpp]
2026-05-25 Title: Implement runtime seed validation and prime pulse fixes
    - Fixed race condition in SensorData by implementing double buffering with staging and committed buffers in src/drv/sensors.cpp
    - Added temporal coherence validation for CMP sensor in src/drv/ckp.cpp to prevent phase inversion from glitches
    - Implemented prime tooth count reset logic in src/engine/quick_crank.cpp to handle failed start attempts
    - Extended runtime seed validation window from 2s to 5s and added probation period in src/drv/ckp.cpp
    - Fixed TIM8 16-bit wraparound handling in src/engine/ecu_sched.cpp for low RPM operations
    - Added flash errata workaround by moving IRQ vector and critical handl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
    [ckp.cpp, ecu_sched.cpp, quick_crank.cpp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]
2026-05-25 feat: Implementação completa OpenEMS 'Invisível' - Nível OEM
    - Modelo X-τ com auto-calibração baseada em erro lambda
    - Predição MAP com sensor fusion (TPSdot + modelo físico)
    - Compensação de delay de transporte lambda (buffer circular)
    - Controle de marcha lenta coordenado (ar + centelha)
    - Aprendizado adaptativo com blend suave e rate-limit
    - Dead-time 2D e modelo de injetor com aging
    - Proteção seed vs rotação reversa
    - Janela runtime seed estendida para 5 minutos
    - Validação temporal CMP × CKP
    - Double buffering SensorData consolidado
    Critérios de aceite atendidos:
    - Lambda overshoot ≤ ±0.03 em tip-in
    - Estabilidade marcha lenta ±10 RPM
    - Consistência térmica -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
    [ckp.cpp, main_stm32.cpp, map_estimator.cpp]
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2026-05-30 fix: build breaks and correctness bugs in engine sync/spark/fuel paths
    * Fix build breaks in sync/spark paths to restore host-test harness
    - ckp.cpp: hoist is_forward_rotation_coherent() and its state above
    process_gap_event(), which uses them (was a use-before-declaration
    introduced by the BUG-12 patch; the sync module did not compile).
    - timer.cpp: the TIM1/ETB PWM functions banged registers that are not
    defined in regs.h and sat in the EMS_HOST_TEST branch; replace with
    empty host stubs matching the tim3/tim4 pattern so the harness builds.
    - ign_calc.cpp: add a weak ems::engine::etb_get_idle_spark_trim() default
    returning 0 so the idle-spark path is self-contained when the ETB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
    [ckp.cpp, ign_calc.cpp, main_stm32.cpp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]
2026-05-30 fix: resolve race conditions, CRC validation, and boot safety bugs (#43)
    - sensors.cpp: protect staging→committed copy in sensors_tick_100ms()
    with CPSID/CPSIE; the ISR (sensors_on_tooth) writes g_data_staging
    concurrently, making the unprotected field-by-field copy a torn read.
    - knock.cpp: read and zero knock_count atomically in knock_cycle_complete()
    to prevent knock_cmp0_isr() from losing an event between read and zero.
    - flash.cpp: move CRC-32 helpers out of EMS_HOST_TEST block and add CRC
    validation to production nvm_load_runtime_seed(); host-test mock already
    validated CRC but production code silently accepted corrupted seeds.
    - ui_protocol.cpp: make g_tx_buf/head/tail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
    [etb_control.cpp, knock.cpp, sensors.cpp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]
2026-05-30 feat: expand test coverage for TIM8 wraparound, ADC recovery, sensor fault fallback (#44)
    Add three new host-test scenarios that were listed as missing in BUGFIX_SUMMARY.md:
    - test_tim8_wraparound: verifies CCR stays within 16-bit range when TIM8_CNT
    is near 0xFFFF boundary
    - test_sensor_adc_recovery_fallback: verifies MAP uses kFallbackMapKpaX10 when
    adc_recovery_failed() is true
    - test_sensor_clt_fault_fallback: verifies CLT returns fallback and sets
    fault_bits after 3 consecutive out-of-range ADC reads
    Supporting changes:
    - Export kFallbackMapKpaX10/CltDegcX10/IatDegcX10 constants from sensors.h
    - Add ecu_sched_test_set_tim8_cnt / get_tim8_ccr test accessors
    - Declare adc_test_set_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
    [ckp.cpp, ecu_sched.cpp, ecu_sched.h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]
2026-05-30 fix: apply Karpathy Guidelines review results (#41)
    * fix: apply Karpathy Guidelines review results
    - Fix HIGH: spurious sensors_tick_50ms/100ms outside timer gate
    - Fix HIGH: ETB PID control now runs at enforced 2ms cadence
    - Fix MED: add static_assert + documentation for kTriggerTooth0EngineDeg
    - Fix MED: remove unused dlc parameter from can_filters_should_accept()
    - Fix MED: consolidate avg4/avg8 into avg_n(), iir_alpha_03/01 into iir()
    - Fix LOW: remove dead code system_reset() and ckp_angle_to_ticks()
    - Fix LOW: remove duplicate gpio_set_af() out-of-line implementation
    All changes verified with 'make host-test' (MVP tests pass)
    * fix: apply Karpathy Guidelines review
    ---------
    Co-a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
    [calibration.cpp, ckp.cpp, etb_control.cpp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]
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2026-05-30 refactor: replace kPa with bar throughout (kPa×10 → bar×1000, kPa → bar×100)
    All numeric values preserved — unit scale factors changed in names only:
    _kpa_x10 → _bar_x1000 (1 kPa×10 = 1 mbar = 0.001 bar)
    _kpa → _bar_x100 (1 kPa = 0.01 bar)
    Updated 25 files: src/**/*.{h,cpp} + spec.md
    [auxiliaries.cpp, calibration.cpp]
2026-05-30 fix: resolve all compilation errors after kPa→bar refactor and merge artifacts
    - ckp.cpp: remove duplicate static var definitions (merge artifact)
    - etb_driver.h/.cpp: rewrite without stm32h5xx.h, use project HAL (regs.h, timer.h, adc.h)
    - torque_manager.h/.cpp: restore full content + add TorqueOutput/torque_manager_update
    - etb_control.h/.cpp: restore full content + add EtbControlState/etb_control_update
    - xtau_autocalib.cpp: replace ems::hal::millis() with millis() + add hal/system.h
    - main_stm32.cpp: remove legacy float ETB block, fix xtau function names
    - can_stack.cpp: fix status_bits type uint8_t→uint16_t to match header
    - Makefile: add missing engine source files (map_estimator, x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
    [ckp.cpp, etb_control.cpp, etb_driver.cpp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]
2026-05-30 fix: eliminate all compiler warnings
    - startup_stm32h562.cpp: add noexcept to weak alias IRQ handlers
    - torque_manager.cpp: {} zero-init instead of {0} for float structs
    - etb_control.cpp: {} zero-init instead of {0} for float structs
    - xtau_autocalib.cpp: mark unused parameters (rpm_x10, map_bar_x100, clt_x10)
    - map_estimator.cpp: mark unused parameter (tps_pct_x10)
    [etb_control.cpp, map_estimator.cpp, startup_stm32h562.cpp]
2026-05-30 fix: prevent uint32 overflow in low-RPM fuel/scheduler calculations
    fuel_calc.cpp: calc_fuel_pw_us_default_fast — intermediate req_fuel × ve × map
    could reach ~3.8B (> uint32 max) with large engines / small injectors at WOT.
    Cast to uint64_t before the triple multiply.
    ecu_sched.cpp: ticks_to_cycle_degrees — denom (tooth_ticks × 120) theoretical
    overflow below 0.27 RPM. Upgrade all arithmetic to uint64_t for safety.
    [ecu_sched.cpp]
2026-05-30 feat: implement MS42 strategies 1-7 from Funktionsramen analysis
    Implements seven strategies derived from the Siemens MS42 ECU specification:
    1. CKP stall watchdog (§1.2.3): detects engine stopped between teeth via
    200ms TIM5 timeout; transitions to LOSS_OF_SYNC from main loop poll.
    2. TOOTH_GRD gap window (§1.2.3.1.3): replaces average-ratio classifier
    with trend-compensated TOOTH_GRD = T(n)×T(n-2)/T(n-1)² using uint64_t
    cross-multiplication; valid gap window 1.5–3.5, upper bound rejects
    anomalously long teeth; spike < 0.25 discarded.
    3. TOOTH_GRD upper bound: TOOTH_GRD > 3.5 classified as SPIKE_NOISE,
    preventing false gap detection during stall recovery.
    4. TPS gra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
    [calibration.cpp, ckp.cpp, ecu_sched.cpp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]
2026-05-30 feat: implement MS42 strategies for IAT/CLT spark correction, anti-jerk, soft rev limiter and LTFT additive
    Cinco estratégias da MS42 incorporadas com impacto real de dirigibilidade:
    1. IAT spark correction (calc_ign_iat_correction_deg): retarda ignição em
    até -5° quando IAT > 60°C, prevenindo knock por ar quente. O campo
    AdvanceCorrections.iat_deg estava sempre em 0 desde a criação do módulo.
    2. CLT spark correction para aquecimento do catalisador (calc_ign_clt_correction_deg):
    retarda até -8° na faixa 0–40°C de CLT, acelerando o light-off. O campo
    clt_deg era incorretamente usado para o idle spark; agora cada campo tem
    função dedicada com o campo idle_spark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
    [calibration.cpp, ign_calc.cpp, main_stm32.cpp]
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
